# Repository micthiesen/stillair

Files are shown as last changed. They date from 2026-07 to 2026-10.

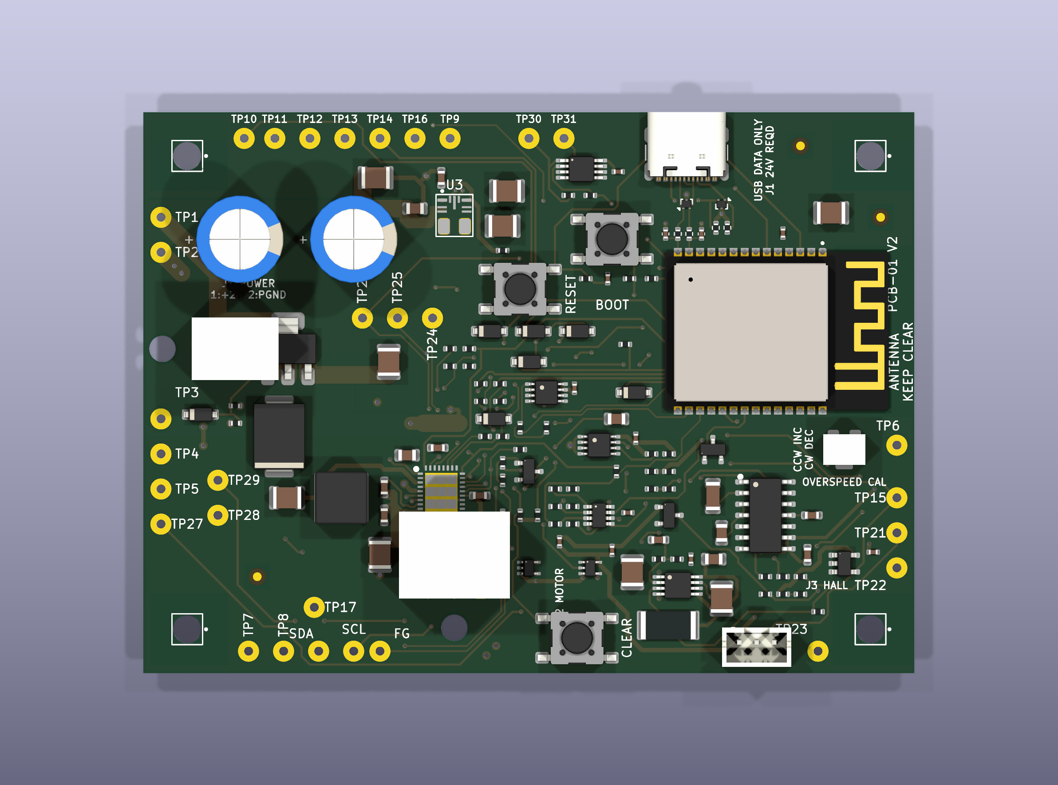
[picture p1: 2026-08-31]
pcb/pcb-01-v2/fab/assembly-preview-3d.png

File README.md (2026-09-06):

# stillair

Custom 44-inch direct-drive ceiling fan for quiet overnight air mixing: CubeMars GL100 KV10
gimbal motor, TI MCF8316D sensorless FOC on a custom controller board, ESP32-C6 supervisor
with local-only Apple Home control via Matter (rs-matter), and an independent analog
overspeed backstop.

This repo is the canonical source for everything except the OnShape 3D model:

- [`docs/`](docs/overview.md) — the full design dossier (start at the overview; current work
  state in [docs/STATE.md](docs/STATE.md))
- [`bom/`](bom/README.md) — parts list with purchase tracking
- [`testing/`](testing/README.md) — commissioning matrix with sign-off fields
- [`firmware/`](firmware/) — Rust `no_std` ESP32-C6 supervisor (stub; contract in
  [docs/controls.md](docs/controls.md))
- [`pcb/`](pcb/README.md): authoritative tscircuit source for new boards plus downstream KiCad
  routing and production outputs (requirements in [docs/electrical.md](docs/electrical.md))
- [`cad/`](cad/README.md) — fabrication outputs (specs in [docs/parts.md](docs/parts.md))

Firmware: `cd firmware && cargo build` (stable Rust; flashing via `cargo run` uses espflash).

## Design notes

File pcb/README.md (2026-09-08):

# PCB

PCB design source and production projects. For new boards, committed tscircuit code owns component
definitions, schematic connectivity, board specifications, and placement. KiCad owns downstream
routing, unsupported fabrication detail, checks, and outputs. The complete electrical requirements
are [../docs/electrical.md](../docs/electrical.md), and the V1-to-V2 gate list is at the bottom of
that doc.

## Projects

- `pcb-01/` — the controller board (**PCB-01**). Captured, routed, and ordered from JLCPCB
  2026-07-30 (order W2026073105230212).
- `pcb-01-v2/` — the fresh **PCB-01 V2** controller project. It is intentionally not cloned from
  V1. Capture, placement, routing, silkscreen, and the submission package are complete; its exact
  authority is [`docs/pcb-01-v2.md`](../docs/pcb-01-v2.md) and its order procedure is
  [`pcb-01-v2/fab/ORDERING.md`](pcb-01-v2/fab/ORDERING.md).
- `pcb-02/` — the 24 × 8 mm DRV5033 Hall daughterboard (**PCB-02**). Created 2026-07-30:
  schematic captured (ERC clean), 2-layer board set up (outline, M2 hole pair as the BR-100
  datum, JLCPCB rules). Ships as its own small order — PCB-01 already went out separately.
- `pcb-03/` - the optional 39.75 x 21.00 mm e-paper display bridge (**PCB-03**). It converts PCB-01
  V2's four-wire temperature I2C expansion path to the SPI and sideband signals used by a
  Waveshare 1.54-inch black/white module. Its authority is
  [`docs/pcb-03.md`](../docs/pcb-03.md); it is a two-layer bare board for hand assembly. Upload
  and quote settings are in [`pcb-03/fab/ORDERING.md`](pcb-03/fab/ORDERING.md).

## Tooling and authority

The pinned local tscircuit toolchain lives in this directory. Run its viewer locally so code and
reviewed placement edits remain in the checkout. The **`/pcb` skill** at
[`.agents/skills/pcb/SKILL.md`](../.agents/skills/pcb/SKILL.md) defines authoring, review, initial
handoff, and later ECOs. KiCad 10 and the project-scoped Konnect server remain available only for
the downstream phase.

An initial handoff exports a new KiCad seed into staging. Once routing starts, a new export must
never overwrite the production board. Later tscircuit changes become an explicit stable-identity
ECO, applied through KiCad/Konnect/native APIs and checked to preserve unrelated routes, vias,
zones, rules, and UUID-bound waivers. Each board declares unsupported downstream work in
`design/kicad-augment.json`.

PCB-01, PCB-01 V2, PCB-02, and the already released PCB-03 remain legacy KiCad-authoritative
projects. PCB-03's new `design/` source recreates it only as a workflow validation fixture through
the KiCad handoff boundary.

Fabrication is planned through JLCPCB; JLCPCB assembly vs hand-population is TBD (prefer
footprints/parts in the LCSC catalog where it doesn't compromise the design, so the PCBA
option stays open). The Hall daughterboard (18 × 8 mm, DRV5033) is a second tiny board that
should ride in the same order/panel. A possible V2 reshape to a horizontal donut board is
noted in the handoff doc.

## Human probing map

PCB-01 test-point and connector locations are retained in `pcb-01/probe-map.json`; the human
workflow, ground-domain rules, and temporary-wire policy are in [`docs/probing.md`](../docs/probing.md).
Use `pcb/tools/probe_guide.py TP7`, `pcb/tools/probe_guide.py J8`, or
`pcb/tools/probe_guide.py TP2 --mode resistance` to print a complete one-step instruction. Run
`pcb/tools/probe_guide.py --verify-board` after any layout revision so the retained map cannot silently
drift from the board.

## JLCPCB order config

The bullets below are the historical V1 research record. They do not control PCB-01 V2. V2 uses
the impedance-controlled JLC041621-7628 build, exact POFV attachments, and assembly split in
[`pcb-01-v2/fab/ORDERING.md`](pcb-01-v2/fab/ORDERING.md).

- Standard 4-layer 1.6 mm with the order-form copper dropdown set to **2 oz outer / 1 oz
  inner** (the V1 order did not use a canned JLC04161H stackup; sanity-check the resulting
  dielectric build in the quote tool). ENIG and the Ø3.2 NPTH holes are unrestricted.
- **2 oz raises min trace/space to 0.15–0.16 mm** — check routing under the ESP module
  fits. The common fallback for a ~2 A board is 1 oz outer with ≥1.5–2 mm pours, avoiding
  the 2 oz penalty entirely; decide at capture.
- MCF exposed-pad thermal vias: request **POFV (copper-filled/capped vias)**, drills
  0.25–0.35 mm — a paid special process at 4 layers; budget it.
- Ballpark: ~$80–150 for qty 5 bare boards with the above; 2 oz doesn't block PCBA.

## Footprint/symbol sourcing (researched 2026-07)

Clean pulls from KiCad official libs: ESP32-C6-MINI-1 (needs KiCad ≥8.0.9), GCT USB4105
(note: **top-mount** — confirm against the housing), TC2030-NL, JST PH and SH/SRSS
connectors, Coilcraft LPS4018, Panasonic EEU-FR (parametric CP_Radial), SMC TVS, SOIC-14,
SOT-23 variants.

Needs Ultra Librarian download + datasheet verification: **MCF8316D** (rectangular-body
VQFN-40 RGF — KiCad's stock VQFN-40 is the wrong shape), **TPSM365R6** (RDN QFN-FCMOD).
Hybrid cases: TPS7A1601A (KiCad footprint, UL symbol; check EP copper vs TI's land),
SN74LVC1G74 DCT/SM8 (KiCad's generic SSOP-8 pad span is wider than TI's spec — use TI/UL's).
All TI discrete symbols come from SnapEDA/UL (pinouts are part-specific). Molex: the ordered
headers are the **right-angle** variants (43045-0200, 43650-0300) — use the horizontal
footprints, not vertical.

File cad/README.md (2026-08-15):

# CAD

Fabrication outputs for the custom mechanical parts: 2D profiles for laser/waterjet (MP-100,
KD-100, MR-100, LS-100, BR-100 flat pattern), CNC files (MC-100, RH-100, SP-100, BL-100
router files), and print files (BA-10/12/14, ENC-100, optionally EB-100).

The full 3D assembly is modeled in **OnShape** and does not live in this repo; export STEP/PDF
here when parts approach fabrication release. Dimensioned specs for every part:
[../docs/parts.md](../docs/parts.md). Do not release motor-dependent metal before the
fabrication gates at the bottom of that doc clear.

## Released files

| Part | Files | Status |
|---|---|---|
| MP-100 | `MP-100_revA.step`, `MP-100_revA.pdf` | Received + owner-accepted 2026-08-14 |
| ST-100 | `ST-100_revA.step`, `ST-100_revA.pdf` | Received + owner-accepted 2026-08-14 |

Name every export `<PART>_rev<X>.<ext>` and commit it **as sent**. The point is that a later
revision diffs against the geometry that was actually quoted, not against the live OnShape
model, which keeps moving.

## Ordering at JLCCNC

Learned ordering MP-100 (2026-07-27). The CNC service is **jlccnc.com**, separate from the
PCB side.

**Send two files.** A STEP (AP214) drives the instant quote and the geometry; a **PDF drawing**
carries everything a STEP cannot hold — threads, tolerances, finish, and face assignment.
JLC's review engineers cross-check the two by hand and will query any disagreement.

**Attach the PDF twice.** Once as the general 2D drawing, and again to the `+ Add file` slot
that appears under **Threads → Yes**. That slot is the "tapping document" and it is easy to
miss; with Threads set to Yes and no file, tapped holes get quoted as plain drills.

**Dialog settings that worked** (adapt material/finish per part):

| Field | MP-100 value | Note |
|---|---|---|
| Material | Stainless Steel → SUS304 | Aluminum 6061 is the sticky default — verify on the quote line, stainless runs 2–3× the price |
| Surface Finish | Brushing | Anodizing is aluminium-only; passivation is not offered for 304 |
| Tightest Tolerance | ±0.10 mm | Only buy ±0.05 if a callout truly needs it |
| Appearance | Standard | Ra 1.6 is not worth paying for on a hidden part |
| Threads | Yes + PDF attached | See above |
| Sub-assembly | No | |

**Their DFM rules that shaped the design** (worth designing to up front rather than
answering a query about later):

- Blind tapped holes want **≥ half the nominal diameter left unthreaded** at the bottom.
  This is what drove MP-100's ten taps to M3 × 0.5 at 3.5 mm thread in a 5.0 mm drill; M4
  needs 2.0 mm of run-out and could not get it inside a 6 mm plate.
- Effective thread length **≤ 3 × hole diameter**.
- Tapped holes must sit in the interior of the part, clear of edges.
- Default tolerance is **±0.1 mm** if the drawing states none — tighter than ISO 2768-m, so
  a 2768 block is a ceiling, not a floor.

**What JLC does not hold: form tolerances.** Flatness, runout, concentricity and true
position are quoted to nothing. They live in the PDF as intent and must be inspected on
arrival. This is the reason SP-100 (0.05 mm concentricity TIR) and MC-100/RH-100 (0.08 mm
flatness and TIR) are poor fits for JLC even though MP-100 was a good one.

**Drawing checklist** (what MP-100's PDF carries):

1. Views labelled `CEILING FACE` and `UNDERSIDE` in words, plus a note assigning every
   one-sided feature to a face. A flat disc looks identical from both sides.
2. A hole table with signed X/Y per hole. Coordinates cannot be mirrored the way
   "6× at 45°, 60° spacing" can.
3. A note fixing the angular datum and direction in prose, as mirror insurance.
4. A note that the hole table covers tapped holes only, if through-holes are dimensioned
   on the views instead.
5. ISO 2768-mK block, form tolerances, minimum internal corner radii, material and finish.

**Turned-part modeling + drawing notes** (learned on ST-100 rev A, 2026-07-28):

- Model the thread-entry chamfer as the Hole feature's **countersink** (Ø7 × 90° for M6):
  it exports in the STEP and lands in the drawing's hole callout automatically.
- Second-end tap on a turned part: **Mid plane** between the end faces + **Feature mirror**
  of the Hole feature — one edit drives both ends.
- In OnShape's tapped-Hole dialog the tap fields (Tapped depth, Tap clearance) are below
  the fold — scroll; the visible 13.44/90° pair is the countersink, not the thread.
- Drawings: the **Datum** tool attaches to the OD silhouette edge or the Ø dimension; the
  **Geometric tolerance** tool only attaches its leader *during placement* (hover-click the
  edge while the dialog is open) — a frame placed floating cannot be attached afterwards.
- Fill the title block TITLE/DWG NO fields before export (left empty on ST-100 rev A;
  harmless, but the shop sees it).

**Gotcha that cost a rebuild:** OnShape hole tables snap their origin to real geometry, so
an under-constrained centre bore silently offsets every coordinate in the table. MP-100's
bore sat 0.64 mm low in Y and the table inherited it. If the table's origin will not snap
where it should, suspect the model, not the drawing — and check that the base sketch is
fully defined before trusting any exported coordinate.

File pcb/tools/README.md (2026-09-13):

# PCB tools

The shared native/workflow helpers are available for future source/native changes.
Stillair has not configured `pcb/workflow.json` or a readiness profile for them.
Installing the tools does not migrate or reaccept PCB-01, PCB-01 V2, PCB-02 or the
released PCB-03. These remain KiCad-authoritative and use their existing commands
and release evidence. Do not copy Crystal Shim's profiles or geometry here.

## One checked change lifecycle

Agree on the visual direction before detailed placement, then record dimensions,
mounting, connector directions, layer roles and assembly limits in canonical specs.
Keep images as references; they do not select circuitry or exact component geometry.
Define every required preparation check before assigning implementation so paste,
service labels and export requirements do not reopen an otherwise finished handoff.

| Stage | Result |
| --- | --- |
| `doctor` | Installed capabilities and project configuration are checked before choosing an automation path. Unsupported operations stay explicit. |
| `begin` | Retains the adopted lock, native file hashes and before snapshot. Begin before editing the native project. |
| `plan` | Rebuilds source, compares the accepted baseline and records the complete target/ECO with its input hashes. |
| `draft-transaction` | Drafts same-side placement changes only and rejects every other plan change. Review associated track/via/zone UUIDs explicitly. A draft is not application or acceptance. |
| `apply` | Runs the supported native transaction against the bound before state, saves and reopens the candidate, then verifies saved readback. |
| `validate` | Runs source checks, strict ERC, source/native parity, fresh native DRC, the complete preparation profile and fresh renders. It does not modify production native files. |
| `review` | Records actual inspection of the current validation/renders across visual contract, schematics, placement/copper and assembly/process. |
| `accept` | Rechecks current inputs, complete checks and resolved review, then advances the existing handoff lock once. |
| `status` | Reports the retained stage; a prior success does not excuse changed inputs. |

The coordinator is `pcb_workflow.py`; run `python3 pcb/tools/pcb_workflow.py --help`
for its current flags. `begin` through `accept` coordinates an ECO to an adopted
source/native handoff. First adoption still uses the staged `tscircuit_handoff.py`
export and acceptance path. A standalone `validate` can audit an existing configured
board but cannot invent the baseline and plan needed for acceptance.

Review can be performed by the agent or owner within existing authorization. The
review record names the reviewer, binds the exact validation object and records
concrete findings/evidence in all four scopes. The tool cannot inspect a picture
or resolve an electrical question on the reviewer's behalf. Apply corrections,
validate again and review the new evidence before final acceptance. Tool failures
and unsupported capabilities do not create new permission gates.

The review JSON has this shape. Replace each placeholder with actual inspection
findings and the current `validation` value from `run.json`:

```json
{
  "validation": "<current validation object SHA-256>",
  "reviewer": "<reviewer name>",
  "scopes": {
    "visual_contract": "<visual and dimensional findings>",
    "schematics": "<schematic and electrical findings>",
    "placement_and_copper": "<placement and layer render findings>",
    "assembly_and_process": "<paste, labels, stack and order findings>"
  },
  "unresolved_findings": []
}
```

## Evidence and configuration

A run has a small `run.json` index and `objects/<sha256>.json` evidence objects.
Identical retained JSON content shares an object within that run. Keep the index,
referenced objects and reviewed renders together. Do not copy repeated full
snapshots into successive closure reports or substitute a bare `passed: true`.
The coordinator binds source, native project files, canonical contracts, reference
images, profiles and checker code. A changed input or modified evidence invalidates
stale validation/review. Canonical docs describe the current target; STATE points to
the current acceptance and remaining routing/commissioning work.

`pcb/workflow.json` and `pcb/tools/readiness-profiles.json` are project-owned.
They select board paths, source commands, specification/image inputs and exact
preparation requirements. They are not shared copies. A missing or unsupported
profile is an explicit configuration failure, never a skipped audit or inherited
permission to use another board's limits.

A reviewed source-checker limitation, when a project needs one, binds the exact
command, nonzero exit code, stdout digest and stderr digest. Its raw failure and
reason remain in the evidence, with required native counterchecks. Any changed
output fails closed. This is an accounted-for checker limitation, not a clean source
check or permission to ignore further findings. Never inherit another project's
limitation record.

`pcb_readiness.py` performs read-only checks of geometry, physical stack, planes,
vias, native rules, routing policy, paste, labels and declared exclusions. It uses
native geometry plus saved settings where SWIG lacks a readable API. Profiles
must declare all supported check categories. Project callbacks retain specialized
checks without embedding product rules in the generic engine. This is preparation
validation, not zero-unconnected routed acceptance or physical commissioning.
Inspect the declared assembly/export contract during final review as well.

## Verified write helpers and limits

Prefer a supported helper over GUI repetition or a new board-specific script.
Discover capabilities first and test uncertainty on explicit scratch copies.
Never infer support from the name of a tool or from a success flag alone.

| Operation | Supported path and limit |
| --- | --- |
| Footprint moves and associated copper; rectangular outlines | `kicad_native.py`, with UUID-bound from/to geometry and explicitly associated items. |
| Pad paste, existing footprint fields, labels | Verified native transaction operations with saved readback. |
| Straight tracks, through vias, simple zones | Verified native operations; complex zone holes, blind/buried/microvias and arbitrary geometry are not implied. |
| Existing netclass sizes | Verified native settings operation; netclass assignment changes are not currently supported. |
| Interactive router preferences | No verified native writer. The in-memory board settings do not prove the GUI session preference was saved in `.kicad_prl`. |
| Existing schematic Value, MPN, Description, Datasheet and Footprint | `kicad_schematic.py`, one explicit leaf sheet and existing string properties only. |
| Schematic Reference rename, new properties, BOM/position/DNP flags | Not supported by the schematic bridge. Use an independently verified operation or the GUI and recheck parity. |
| Physical stack materials/thickness | No verified automated writer in these helpers. KiCad 10 SWIG exposes an opaque stack descriptor; enabling layers does not set the physical stack. |
| Custom-rule file installation | No verified native installer in the helper. Use the supported GUI path; native CLI DRC verifies the installed adjacent rules. |
| Footprint replacement | Not implemented by the generic native transaction. Requires source-aware footprint/pad identity mapping and a verified application path. |

Read exact operations with:

```sh
sh pcb/tools/kicad_python.sh pcb/tools/kicad_native.py capabilities
python3 pcb/tools/kicad_schematic.py --help
```

Use `sh pcb/tools/kicad_python.sh pcb/tools/kicad_native.py inspect --board PATH`
to obtain UUIDs, exact current states and input hashes without writing a discovery
script. The returned saved state supplies transaction `from` values.

Native transactions bind every project input in `before_files`, preflight the whole
batch, load the actual project settings, fill, save and reopen a scratch candidate,
and compare each requested result and saved readback before publication. Native publication replaces files
individually; it is not atomic across a project. Transaction/editor locks and stale
hash checks protect known concurrent changes. Keep the project closed during an
apply. A publication failure attempts guarded rollback and retains recovery files
when it cannot restore safely. Read the reported state instead of retrying blindly.
A native-application receipt alone does not prove electrical correctness, DRC or
acceptance; the external validator and workflow gates establish those separately.

Schematic batches use Konnect's local stdio MCP binary, not an external account.
The wrapper runs the batch on a scratch leaf, verifies every requested property
and the entire semantic tree, compares fresh native net connectivity, and atomically
publishes only verified Konnect-produced bytes. It refuses ambiguous/duplicate
properties, missing fields, partial results, stale inputs and unexpected changes.
Quotes, backslashes and control characters in edited old/new values are deliberately
unsupported while the installed upstream string handling remains unsafe.

Example request for an existing leaf property:

```json
{
  "schema_version": 1,
  "before_sha256": "<SHA-256 of the current leaf schematic>",
  "edits": [{"reference": "J1", "fields": {"MPN": "NEW-PART-NUMBER"}}]
}
```

Pass this JSON to `kicad_schematic.py leaf.kicad_sch request.json --receipt receipt.json`.
Use `--konnect-command` and `--kicad-cli-command` with JSON argv arrays to select the
installed executables. A root schematic containing hierarchical sheets is not the
leaf containing a component. All wrappers use argv arrays rather than shell code.

The [shared Konnect skill](../../.agents/skills/konnect/SKILL.md#choose-the-write-path-before-implementation)
links the inspected 0.2.1 implementation: single-component `fields` are ignored,
annotation appends duplicate keys, batch edits can partially succeed or corrupt
quoting, and design/layer-rule setters write the wrong KiCad 10 locations. These
are measured limits, not reasons to repeat the same failing calls.

## Stillair commands and existing handoff

Use the local PCB-03 source checks and established board-specific tools below.
Before enabling the coordinator, define a Stillair-owned profile for a compatible
adopted source handoff, supported readiness checks, canonical specifications and
actual runtime commands. Missing configuration is explicit; no released board has
been implicitly audited by this sync.

The generic stdlib suites run without a board:

```sh
python3 -m unittest discover -s pcb/tools -p 'test_kicad_*.py'
python3 -m unittest discover -s pcb/tools -p 'test_pcb_*.py'
```

Native integration tests require an installed KiCad runtime and use scratch
projects. Record actual runtime evidence separately from skipped tests.

`tscircuit_handoff.py` is the new-board boundary. It validates normalized authoritative source,
stages the one-time KiCad export, records an accepted lock, and plans later ECOs without writing a
production KiCad project.

Acceptance is byte-bound to every staged `.kicad_*` file listed in `handoff-receipt.json`. Moving
the complete stage directory is safe, but changing its board, root schematic, or child schematic
after staging makes `accept` fail. Native staging and acceptance are currently macOS-only.

The initial exporter fixture may retain only the differences explicitly declared by
`schematic_cleanup`; its receipt lists each reference, expected value, and observed value. After
performing that cleanup in KiCad, run this against the current root schematic before routing or
fabrication:

```bash
python3 pcb/tools/tscircuit_handoff.py verify-schematic-cleanup \
  pcb/dist/pcb-03/design/design-manifest.normalized.json \
  --augmentation pcb/pcb-03/design/kicad-augment.json \
  --schematic /path/to/current/root.kicad_sch \
  --output /path/to/schematic-cleanup-report.json
```

The command invokes the discovered `kicad-cli` itself and derives the XML netlist and JSON ERC in
one temporary run, so separately supplied or stale reports cannot pass. It requires error,
warning and excluded severities, rejects ignored checks and any excluded finding, and
then requires exact references, values, symbol IDs, footprints, MPNs, Datasheets, pin sets, net
endpoints, and a clean ERC result. A failing report must not be used to start routing.

`check_drc.py`, `jlc_fab.py`, `refill_zones.py`, `render_board.sh`, `probe_guide.py`, and the
board-specific `pcbnew` augmentation scripts are downstream KiCad tools. Their writes use KiCad's
native API and must follow the protected-file and preservation checks in the `/pcb` and `konnect`
skills.

The PCB-01 placement planners (`board_model.py`, `check_moves.py`, `check_plan.py`,
`make_briefs.py`, `park_unplaced.py`, `place_targeted.py`, and `validate_group.py`) are retained only
as legacy analysis/history. They are not an authoring or update path for a tscircuit-first board.
The two scripts that directly rewrote protected KiCad text were removed; git history retains them.

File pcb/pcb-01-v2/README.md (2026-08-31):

# PCB-01 V2 KiCad project

Production-intent KiCad 10 project for the 88 x 64 mm PCB-01 V2 controller. The schematic,
footprints, exact ratsnest, four-layer board setup, placement, rule areas, copper zones, keepouts,
fiducials, silkscreen, and assembly metadata are complete. All 166 footprints are on the component
side. Routing and zone fill are complete. The reviewed headless DRC has zero active violations and
zero unconnected items; its 21 exact UUID-bound exceptions are documented in
`../tools/check_drc.py`.

The frozen circuit and layout authority is
[`docs/pcb-01-v2.md`](../../docs/pcb-01-v2.md). Do not import V1 routing, placement, zones, probe
coordinates, or DRC waivers.

## Routing rules retained for review

Open `pcb-01-v2.kicad_pro` and route in the PCB Editor. The concise interactive routing checklist is
<https://mcp.syas.ca/boris/artifacts/art_eon2bpkmslvmtf6wfpa>.

Use the deliberately small routing vocabulary encoded in `pcb-01-v2.kicad_dru`:

| Use | Track | Via |
|---|---:|---:|
| Signals and sensitive analog | 0.20 mm | 0.60/0.30 mm |
| Local rails and 3V3 | 0.50 mm | 0.60/0.30 mm |
| RAW24, VM24, and PGND | 2.00 mm | 1.00/0.50 mm |
| PHASE_U/V/W | 2.00 mm | none |
| USB D+/D- pair | 0.20 mm, 0.20 mm gap | none |

The only narrower power exceptions are the named, tightly bounded U1 and U3 pad-escape areas. The
rules require the complete track item to remain inside the area. Widen immediately after the pad.
U1's three PGND returns use reviewed 0.60/0.30 mm escape vias because its 0.50 mm pin pitch cannot
fit the ordinary 1.00/0.50 mm power via while preserving phase clearance. The headless DRC wrapper
waives only the diameter and drill findings for those three exact via UUIDs.
Do not weaken or delete the PGND routing boundary, antenna keepout, 0.80 mm noisy-to-sensitive
clearance, mounting-hole keepouts, or fiducial keepouts to complete routing.

The stack is 1.6 mm FR-4, four layers, with 2 oz outer and 1 oz inner copper. In1.Cu is the AGND
plane. In2.Cu contains the 3V3 region and motor-region copper defined in the board. Ordinary minimum
clearance is 0.20 mm; 24 V and motor-phase clearance is 0.25 mm; copper-to-edge is 0.50 mm.

## Current verification state

- ERC: zero violations.
- Schematic parity: 159 refs, 78 named nets, and 411 endpoints match the frozen schedule.
- Board: 166 top-side footprints, completed routing, filled zones, and no unconnected items.
- DRC: zero active violations and zero unconnected items, with 21 exact reviewed exceptions for
  bounded pad escapes and three U1 PGND escape vias.
- Probe map: 31 test points and four pin-mapped connectors match the board.
- Assembly export: 55 machine BOM lines, 119 top-side CPL placements, and six hand refs.

After any board edit, refill all zones and rerun the complete release generator. It refuses to emit
orderable Gerbers if ERC, schematic parity, DRC, or probe-map parity fails.

Useful checks from the repository root:

```bash
kicad-cli sch erc pcb/pcb-01-v2/pcb-01-v2.kicad_sch
python3 pcb/tools/check_drc.py
kicad-cli sch export netlist --output /tmp/pcb-01-v2.net pcb/pcb-01-v2/pcb-01-v2.kicad_sch
python3 pcb/tools/check_v2_capture.py /tmp/pcb-01-v2.net
python3 pcb/tools/probe_guide.py --map pcb/pcb-01-v2/probe-map.json \
  --board pcb/pcb-01-v2/pcb-01-v2.kicad_pcb --verify-board
python3 pcb/tools/jlc_fab.py pcb-01-v2
```

## Fabrication handoff

The tracked `fab/` directory contains the exact LCSC map, assembly/hand manifests, machine BOM,
CPL, POFV coordinates, fabrication notes, and a generated four-page assembly locator. U1's twelve
0.30 mm pad-41 holes require epoxy fill and copper capping. U1 pad 41 retains its submitted top
solder-mask aperture for soldering, with no separate bottom aperture. The Excellon and KiCad
coordinate conventions are identified in the generated POFV attachments. U3 pads 4 and 5 are
mask-defined and require JLC engineering confirmation.

Run `python3 pcb/tools/jlc_fab.py pcb-01-v2` immediately before upload, verify
`fab/release-manifest.sha256`, inspect the generated Gerbers, drill map, BOM, CPL, POFV attachments,
and assembly orientation guide, then follow `fab/ORDERING.md` and `fab/fabrication-notes.md`.

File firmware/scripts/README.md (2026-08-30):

# Commissioning scripts

Build the host harness once, then run each file against the same long USB harness used for
bench or ceiling work:

```sh
cd firmware
cargo build
target/debug/stillair --port /dev/cu.usbmodem2101 script scripts/01-board-smoke.txt
```

The numbered release scripts 01 through 06 remain the normal commissioning flow. The retained
unloaded-tuning profiles are evidence-oriented bench tests:

- `18-unloaded-startup-camera.txt`: one complete 35 RPM start, hold, and normal stop.
- `22-unloaded-timestamped-ladder.txt`: both rising and falling speed plateaus.
- `23-unloaded-reverse-ladder.txt`: reverse startup, range, and normal stop.
- `25-unloaded-start-repeatability.txt`: two complete starts and stops per direction.
- `26-unloaded-100-endurance.txt`: ten-minute continuous midrange hold.
- `27-unloaded-140-endurance.txt`: five-minute upper-range hold for the 19.4 V bench source.
- `29-unloaded-100-estimator.txt`: known-stable 24 V observer/current reference point.
- `30-unloaded-24v-ceiling-diagnostics.txt`: guarded 100/140/160/170 RPM ladder with an
  observer/current sample at every rung.
- `31-unloaded-acoustic-threshold.txt`: guarded 100/120/130/140 RPM comparison used when a
  candidate changes high-speed commutation noise; it deliberately stops below 160 RPM.
- `32-unloaded-speed-pi-candidate.txt`: shorter 100/130/140 RPM A/B profile for iterating one
  speed-loop gain while retaining a stable reference and pre-threshold control.
- `33-unloaded-140-observer-onset.txt`: continuous q-axis/BEMF observer capture through the
  apparent 140 RPM optical-hunting onset; precise Hall timing later proved it was tracker slip.
- `47-unloaded-full-range-tach.txt`: 100/140/160/170 RPM plateaus with sampled Hall
  edge-period estimates and MCF FG as the shaft-speed authorities.
- `48-unloaded-pwm-acoustic-candidate.txt` and `49-unloaded-pwm-top-speed-candidate.txt`:
  matched-speed camera-audio, Hall, FG, and wall-power comparisons for PWM tuning.
- `50-unloaded-170-endurance.txt`: ten-minute worst-case unloaded hold at the user ceiling.

A failed command stops a file and returns non-zero. `wait speed` requires both the commanded
ramp and three consecutive FG samples in range, so merely crossing a setpoint does not count
as arrival. `dwell` requires a live 1 Hz telemetry heartbeat and a continuously running state
while an external camera and power logger gather the continuous evidence.

`08-flash-and-unloaded-profile.sh` is the common synchronized acquisition runner. Its default
`STILLAIR_CONFIG_MODE=stage` preserves the unloaded workflow: it builds, flashes, power-cycles,
stages the volatile image, and runs one of those profiles. `STILLAIR_CAMERA_URL` is required for
synchronized recording and physical-motion analysis. The credential-bearing URL is fed to FFmpeg through a private
file descriptor rather than exposed in its arguments or logs. The wrapper waits for a real
camera frame and a live Utility Plug power sample, retains camera audio when the stream provides
it, records the camera-to-motor offset, and fails if the camera, plug logger, controller
telemetry, tracking, or a relevant direction/stall/plateau gate fails. Optical speed is scored
through 140 RPM. Above that, repeatable orientation-specific tracker slips make precise Hall
edge timing and MCF FG the speed authorities while the camera remains the gross-motion guard.
Its deadline is
derived from the selected profile, so endurance profiles do not need a manual timeout override.
Any failed command releases the serial client, attempts controller disarm, then independently
switches off the exact Kasa `Utility Plug`; a successful run leaves the 24 V supply available.
An unloaded run stages and read-back-verifies the volatile MCF image. A loaded reference run uses
`STILLAIR_CONFIG_MODE=verified`, requires the stored golden image to verify, and refuses to replace
a failed baseline with a staged image. `STILLAIR_SKIP_FLASH=1` skips only the ESP build/flash.
Timestamped dwell
profiles also align their camera motion and 1 Hz AC power samples to the same motor timeline, so
`analyze_profile_plateaus.py` and `analyze_profile_power.py` report physical regulation and input
power for the same settled windows. Use
`utility-plug.sh status|on|off|cycle` for manual control and `utility-plug.sh log --for SECONDS`
for 1 Hz AC voltage/current/power evidence. The controller runs inside the Boris Homebridge
container, where Kasa credentials already live, refuses any device other than the pinned Utility
Plug identity and address, and reconnects boundedly after transient TPAP failures without running
periodic rediscovery through an active evidence stream.

The runner uses the ESP32-C6 native USB Serial/JTAG port. Power the board normally, hold BOOT, tap
RESET, release BOOT, then run the flash step. USB VBUS does not power the board. Set
`STILLAIR_PORT=/dev/cu...` to override detection. There is no FTDI/UART transport, VID/PID-specific
adapter logic, or RTS/DTR automation.

`check-mcf-presence.sh` is the safe repeated check after connector cleanup or probing. It powers
the controller, holds one serial connection through boot, passes only when the MCF8316D answers the
firmware's wake-and-address scan, and returns Kasa power off on every exit. Override automatic board
port detection with `STILLAIR_PORT=/dev/cu.usbmodem...` when needed.

`check_board_usb.py` is the permission-independent native-USB check. It passes only when macOS's
live I/O Registry contains exactly one ESP32-C6 USB Serial/JTAG device (VID `0x303a`, PID `0x1001`)
continuously for 0.5 seconds. Serial `/dev` nodes are reported separately and do not decide the
enumeration result. Run it while connecting or resetting the board:

```sh
firmware/scripts/check_board_usb.py
```

Exit 0 means enumerated, 1 means not detected during the polling window, 2 means ambiguous or
unstable, and 3 means the host probe itself failed. A nonzero result never claims which hardware
element caused the failure.

For recovery or A/B work, script 03 begins with `config stage`. This loads and
read-back-verifies the reviewed GL100 first-spin settings in volatile shadow only. It must be
repeated after every motor-power cycle, and it never commits EEPROM. A fresh unverified
controller remains in `SafeBoot`; this prevents zero factory speed-loop gains from invoking
implicit MPET on an ordinary run command. Script 02 remains on hold until the volatile image
has also been reviewed for loaded MPET.

Scripts 04 through 06 are loaded release tests. They begin with `config check` and require the
committed golden image; staging the provisional image there would overwrite loaded tuning.

## Autonomous loaded reference

`09-run-loaded-profile.sh` is the fail-closed entry point for the first exposed loaded capture.
It validates the profile before connecting to hardware, forces verified-golden mode, and requires
the fixed dedicated microphone, OWON capture, camera motion guard, controller telemetry, physical
Hall/FG, and Utility Plug evidence. It defaults to `51-loaded-golden-baseline.txt`, which measures
50, 60, 80, 120, and 170 RPM and returns to verified `idle_off`. It will not accept `config stage`,
`config apply`, raw register writes, an out-of-range speed, an unsafe direction change, or a profile
that lacks a final stopped-state proof.

```sh
STILLAIR_DRY_RUN=1 scripts/09-run-loaded-profile.sh

STILLAIR_CAMERA_URL='rtsps://…' \
STILLAIR_SCOPE_ISOLATED_CONFIRMED=1 \
scripts/09-run-loaded-profile.sh
```

When `STILLAIR_CAMERA_URL` is unset, the runner reads the RTSP URL from
`${XDG_CONFIG_HOME:-$HOME/.config}/stillair/camera-url` or the path named by
`STILLAIR_CAMERA_URL_FILE`. Keep that file outside the repository and readable only by its owner.

The microphone defaults to the AVFoundation device name `Razer Seiren V3 Mini`; override
`STILLAIR_AUDIO_DEVICE` if the enumerated name differs. Audio is retained as mono 24-bit/96 kHz
WAV and analyzed at 48 kHz, preserving comparison bands through 20 kHz. The scope recipe defaults
to `scope-loaded-startup.json`: SOX and FG at 250 ksample/s in discrete 5,000-sample frames. Its
range, offset, ground references, and isolated VDS1022I model must be physically confirmed before
setting `STILLAIR_SCOPE_ISOLATED_CONFIRMED=1`. The capture uses the Python API from
`florentbr/OWON-VDS1022` pinned at commit `4c67805713906c20b4414b4225fd293adea4cb05`; it records
inter-frame arrival gaps and never describes the frames as continuous acquisition.

Each successful run prints a `run_dir` under `STILLAIR_EVIDENCE_ROOT` (default `/tmp`). Its
`manifest.json` records the git commit, timing anchors, configuration mode, file sizes, and SHA-256
hashes for every retained file, including each scope frame. A missing or malformed required source
fails the run. Both loaded wrappers require the repository to remain clean and on the same commit
for the complete run, so the recorded commit identifies the firmware source rather than merely the
latest nearby revision. The baseline entry point deliberately captures the untouched golden reference only. Loaded
candidate generation remains a separate tuning step.

After the untouched reference is secured, run one allowlisted golden-derived candidate with the
same evidence stack and matched ladder:

```sh
STILLAIR_DRY_RUN=1 scripts/10-run-loaded-candidate.sh pwm-30khz

STILLAIR_CAMERA_URL='rtsps://…' \
STILLAIR_SCOPE_ISOLATED_CONFIRMED=1 \
scripts/10-run-loaded-candidate.sh pwm-30khz
```

`10-run-loaded-candidate.sh` accepts `pwm-20khz`, `pwm-25khz`, `pwm-30khz`, `pwm-40khz`,
`pwm-50khz`, `pwm-60khz`, `deadtime-off`, `deadtime-on`, `slew-125v-us`, or `slew-200v-us`.
It verifies the stored golden image before evidence collection, then `config tune` restores that
complete image in volatile shadow, changes exactly the named reviewed field, rechecks the preserved
golden bits, and reports the distinct `config=tuning` verdict. The matched motor profile is
`52-loaded-acoustic-candidate.txt`. The run manifest records the candidate name, application time,
and device reply. No candidate path can commit EEPROM. Retain the golden run as the A/B control and
never promote a finalist until it repeats the release gates.

`02-mpet-and-capture.txt` prints the raw extraction result and then a paste-ready configuration
image. Review that capture before committing or applying it. MPET itself updates shadow
registers only and does not spend an EEPROM cycle.

The 35 RPM design target was rejected for loaded use after one arbitrary-position start rocked
without acquiring. The provisional released floor is 50 RPM; scripts that retain a 35 RPM bench
rung are unloaded evidence profiles, not the user operating contract.

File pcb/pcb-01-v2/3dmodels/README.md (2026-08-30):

# PCB-01 V2 local 3D models

- `ESP32-C6-WROOM-1.STEP` is Espressif's module model. Its corner-origin model is offset in the
  footprint by (-9, -12.75) mm so the 18 x 25.5 mm body aligns with the official land pattern.
- `J1_43045-0200_ENVELOPE.stp` and `J2_43650-0300_ENVELOPE.stp` are conservative body-envelope
  solids built from the exact KiCad F.Fab extents and Molex customer-drawing maximum height. They
  replace nonexistent KiCad package paths and validate board/enclosure access; they are not detailed
  cosmetic connector models.
- `RV1_3224W_ENVELOPE.stp` is the corresponding Bourns body-envelope solid from the exact F.Fab
  extents and maximum body height.

Footprints, courtyards, holes, and fabrication data remain authoritative. These local solids are
mechanical review aids and must stay aligned with their footprint origins.

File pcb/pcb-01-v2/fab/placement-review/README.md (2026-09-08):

# PCBA placement and polarity review, 2026-09-07

## Verdict

The shown DFM for `SMT026083161536_Y8` passes the placement/polarity review. No correction is
required. Michael may confirm it to JLCPCB. No assembly approval or reply was submitted by the
agent. The authenticated order page now shows the PCB production file as **Confirmed**, while
assembly is Pending and awaiting the email response.

Review combined native KiCad pad extraction, the released orientation drawings, independent IC
and discrete-device checks, the emailed image, and the live DFM's component and package data.

## Retained evidence

- `jlc-dfm.png`: supplied 1778 x 1474 image; SHA-256
  `4e52a0c6db225b7a15c2d5958db3682f9cdc68ff9ffdd2808f33bb6ce737dfa1`.
- `factory-bom.zip`: live `Smt_Hw_Bom_Merge` download, containing the factory reference list,
  original coordinates, adjusted coordinates, rotation conventions, package UUIDs, and mount flags.
- `factory-preview.zip`: live `Smt_Hw_Web_File` download, containing the CAM preview geometry.
- `factory-packages.json`: the public package geometries requested by the live DFM viewer.
- `cpl-comparison.json`: full 119-reference comparison, including raw origin/rotation differences
  resolved below. Raw differences in this file are not unresolved placement failures.

Live DFM was opened from the order's **DFM Analysis** link. All 119 unique assembled designators
match `cpl-jlcpcb.csv` and the exact LCSC codes in `assembly-manifest.csv`. All are enabled on top;
there are zero bottom-side parts, missing references, or extra references. The original coordinates
and rotations retained by the factory match the submitted CPL exactly.

## Polarity and direction

Directions refer to the component-side image with J4 at the top.

| References | Required and shown orientation | Result |
| --- | --- | --- |
| U1 | Pin 1 northwest; white package dot northwest | Pass |
| U2 | Pin 1 northeast; antenna east toward board edge | Pass |
| U3, U4, U5, U6, U7, U9, U10, U11, U12 | Pin 1 northwest | Pass |
| U13 | Pin 1 southwest, USB_DP | Pass |
| U14 | Pin 1 northeast, USB_CC1 | Pass |
| D1, D3, D4, D5, D6, D7, D8 | Cathode band west | Pass |
| D2 | Cathode band south; anode north | Pass |
| D9 | Pin 1 northwest; lone lead east | Pass |
| Q1 | Gate/pin 1 southwest; drain tab north | Pass |
| Q2 | Gate/pin 1 northwest; lone drain lead east | Pass |
| Q3 | Gate/pin 1 southwest; lone drain lead north | Pass |
| J4 | Opening north toward board edge | Pass |
| RV1 | Pin 1 northeast; wiper south; screw southwest | Pass |
| SW1, SW2, SW3 | Contact rows and body align with horizontal pad pairs | Pass |

U13 and U14 intentionally face opposite directions, matching the dedicated released callout.
All factory-installed capacitors are nonpolar ceramic MLCCs; their pink dots are library pin
markers, not electrical polarity requirements. Resistors and L1 are nonpolar. The six hand-installed
references C1, C2, J1, J2, J3, U8 are correctly absent, as are DNP C44/C45.

## Coordinate differences resolved

Factory CAM coordinates use `x=x_CPL-50`, `y=y_CPL+119` in mm (CPL Y is negative). For 116 of 119
parts the adjusted placement reference lies within 0.01 mm of this transform. Three packages use
different reference origins; raw rotations also differ by library convention. Their geometry,
not matching raw angle numbers, determines correct placement:

- **U2:** raw adjusted X differs by -2.98465 mm. Transforming the actual factory package places
  all 28 perimeter pins within 0.01036 mm of their native pad centers, with antenna east. The
  package reference is near the electrical-pin/non-antenna center, rather than the entire module
  centroid. The factory model's nine inner ground squares differ from native lands by about
  0.2495 mm in Y; both are 0.8 mm squares with ground-contact overlap. This is a library-land
  difference, not evidence to shift the component away from its aligned perimeter pins.
- **U3:** raw adjusted Y differs by +0.57101 mm. All eleven transformed library pads map to
  their corresponding native lands. Land dimensions/centers differ by up to about 0.1002 mm;
  terminal-facing edges align (pad 2 inner X edge 84.649848 versus native 84.650 mm; pad 9 south
  Y edge 60.341516 versus native 60.350 mm). The factory body drawing also differs by about
  0.204 mm from native F.Fab artwork. These are drawing/reference differences, not the apparent
  0.571 mm whole-component shift.
- **J4:** raw adjusted Y differs by -1.20699 mm. Using the actual contact-metal polygons in
  `customData.pinsInfo[].weldingID`, all sixteen contacts fall inside their intended copper pads.
  Individual signal lead centers differ by at most 0.00022 mm in X and 0.00516 mm in Y. Shell
  stakes fit their slots and the model pegs fit nominal hole clearance. Mouth faces north. The
  library's recommended PAD centers are not identical to physical contact centers.

## Interpretation and sources

This confirms the intended assembly placement represented by this DFM and its part list. It does
not certify the eventual solder joints or actual reel markings. Some tiny model surfaces, notably
U3/U12, do not show a separately legible physical pin-1 mark; their DFM pin-1 markers and mapped
package geometry agree with the released design.

The discrete reviewer checked primary polarity/package drawings:
[MMSZ5242B](https://www.diodes.com/datasheet/download/MMSZ5242B.pdf),
[SMCJ24A](https://www.diodes.com/datasheet/download/SMCJ24A.pdf),
[Vishay BAT54W](https://www.vishay.com/docs/86409/bat54w-g.pdf),
[BAT54SLT1G](https://www.onsemi.com/pdf/datasheet/bat54slt1-d.pdf),
[DMP6023LE](https://www.diodes.com/datasheet/download/DMP6023LE.pdf),
[2N7002K](https://www.diodes.com/datasheet/download/2N7002K.pdf), and
[Bourns 3224](https://www.bourns.com/pdfs/3224.pdf).
Vishay BAT54W datasheet terminal numbering differs from KiCad's generic diode numbering; compare
the cathode band and electrical polarity, not those numbers directly.

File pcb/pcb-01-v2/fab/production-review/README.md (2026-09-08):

# Production-file review, 2026-09-07

Order `W2026083117295494`, PCB job `Y8-12177845A`, assembly `SMT026083161536-12177845A`.

## Evidence and findings

`2026-09-07-jlcpcb-production.zip` is the unmodified 4,462,522-byte authenticated download.
SHA-256: `8312b1b6e856da0d860cf55d4d4389c77a769aa38c311ff671a09dd33e2066e9`.
ZIP integrity passed. CAM Gerbers are in `ok/`; the ODB++ archive is `ok/12177845a_y8.tgz`.
These are returned factory evidence, not replacements for the released KiCad files or Gerbers.

- ODB++ `steps/edit/profile` is 88 x 64 mm. The `set` panel is 88 x 74 mm with 5 mm top/bottom
  process rails. Comparing submitted Gerbers with set CAM in mm requires
  `x_cam=x_submitted-50`, `y_cam=y_submitted+119` (submitted Gerber Y is negative).
- `misc/ImpedanceInfo` records all three approved width/edge-gap settings: `10.77/14.82 mil`,
  `12.87/38.30 mil`, and `12.87/46.18 mil`, each targeting 97 ohm on `tl/l2`.
- Parsed CAM `ts` and submitted `F_Mask.gts` confirm U3 pads 4/5 retain the 1.34 x 1.84 mm openings
  to Gerber rounding precision. Their board-local lower-left positions are `(33.630,50.055)` and
  `(36.030,50.055)` mm after removing the rail offset. Other nearby openings were enlarged by CAM;
  these protected apertures were preserved.
- Parsed CAM `drl` confirms all twelve 0.30 mm U1 pad 41 holes at the submitted CSV coordinates.
  Hole presence does not prove epoxy filling and copper capping. Inspected tools/metadata did not
  explicitly establish that treatment.

This was a targeted geometry/metadata check, not exhaustive copper/netlist equivalence, verification
of every compensated CAM trace width, or final assembly orientation review. The customer-facing
phrase "everything else looks good" must not be interpreted as proof those additional checks ran.
The separate Confirm Parts Placement gate remains outstanding.

## Submitted request

Michael reported submitting the confirmation/modification request on 2026-09-07. Prepared text:

> I have reviewed the production files and they look good. Before approving, I need confirmation
> that all twelve 0.30 mm holes inside U1 exposed pad 41 will be epoxy-filled and copper-capped
> (POFV), as specified in the previously submitted pofv-locations.csv and pofv-location-map.pdf.
>
> Please keep U1 pad 41's top solder-mask aperture open and add no bottom mask openings for these holes.
>
> This is the only outstanding item. If this treatment is already included, no modification is
> needed; please confirm it in writing.

`PCB-01-V2-POFV-support.zip` contains the existing PDF map and coordinate CSV from `fab/`.
A verified copy was supplied on Synology's `overflow` share for phone access. Actual attachment
upload was not independently verified. Michael mentioned a $2 cutting/remarks fee but asked to
disregard speculation about its purpose; the fee is not evidence of POFV treatment.

Await written confirmation, then compare any revised files with this archive and the release.
Do not repeat answered impedance questions unless the relevant geometry, stack, or copper changes.
No production approval was submitted by the agent.

## Download recovery

The first phone download was a 110-byte JSON error (`code:500`, `data:null`). The logged-in browser
download succeeded. **Confirm Production file** opens the review form; approval requires a separate
choice and Submit. Read the Download Production file anchor's actual href and fetch its bytes in
the authenticated page. Browser-control exposes `fs` and `Buffer` directly; `require` is unavailable.
Verify ZIP integrity before treating a download as production evidence.

## Factory confirmation received

Chian subsequently confirmed in writing that all twelve 0.30 mm via-in-pad holes inside U1
exposed pad 41 are filled with non-conductive epoxy and copper-capped; the top pad aperture remains
open and no bottom mask openings were added. Chian explicitly states that the treatment was
already included in the current production file. This clears the POFV process question; the
earlier review had not established the treatment, rather than proving it absent.

The accompanying [image](pofv-confirmation.png) identifies U1 and the correct 3 x 4 hole array,
with an arrow to the CAM `sk` layer. The written statement, not the screenshot alone, confirms
the fill/cap process. Michael may approve the reviewed PCB production file on this basis.
Actual approval has not yet been reported; assembly placement remains a separate later check.

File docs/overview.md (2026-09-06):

# Stillair overview

A quiet, low-profile 44-inch direct-drive ceiling fan for gentle overnight air mixing, with
local-only Apple Home control (Matter over Wi-Fi) and a minimal wood-and-white ceiling
presence. This repo is the
canonical source for the whole project: planning docs, BOM, firmware, CAD drawings,
authoritative tscircuit PCB source, and downstream KiCad boards. The full 3D model lives in
OnShape; everything else lives here.

## Key numbers

| Parameter | Value |
|---|---|
| Maximum rotor diameter | 44 in (1117.6 mm); 42 in fallback |
| Power bus | 24 V low-voltage, certified external supply |
| Target operating range | 35–170 RPM (minimum released only after qualification) |
| MCF driver speed limit | 180 RPM |
| Independent analog trip | 200 RPM nominal |
| Total ceiling drop | ≤10 in (254 mm absolute envelope) |
| Wall clearance | 5.5 in per side at 44 in diameter |
| Ceiling-to-blade gap | 8.0–8.2 in to nearest blade surface |
| Blades | Three symmetric 9 mm birch, 12° nominal pitch |
| Room | 55 in wide, 96 in ceiling, mattress top at 22 in; Vancouver, BC concrete condo |

## Architecture

Direct drive, low voltage, simple structure:

- **Motor**: CubeMars GL100 KV10 low-cogging gimbal motor (24 V, 20 pole pairs). Its KV10
  winding reaches the target speed with low phase current, giving the controller an easy
  low-speed operating point.
- **Drive**: TI MCF8316D sensorless FOC driver with integrated FETs, on a custom 78 × 58 mm
  four-layer controller PCB. The V1 board doubles as the development board (no TI evaluation
  module needed). V2 is only a contingency or optional later redesign; it may be smaller and does
  not inherit the V1 outline automatically. See [pcb-01-v2.md](pcb-01-v2.md).
- **Supervisor**: ESP32-C6-MINI-1-H4 running Matter over Wi-Fi (rs-matter, pure Rust), used
  from Apple Home. It configures the MCF over I²C and commands speed/direction; it never
  switches motor phases.
- **Power**: Mean Well GST60A24-P1J 24 V / 60 W certified supply, wall-side 3 A fuse and
  physical cutoff. Only low voltage crosses the ceiling.
- **Safety**: independent one-pulse Hall speed sensor → LM2907 → TLV1701 analog 200 RPM trip,
  hardware watchdog, and a permission latch that firmware can clear but not force. Mechanical
  backstops: a non-contact central rotor catcher and a separate rated whole-assembly tether.
- **Structure**: compact stainless ceiling plate, three aluminum standoffs, aluminum motor
  carrier and rotor hub, printed BP-100 blades, and a two-motion printed
  [housing](housing.md) with separate stationary and rotating sections.

## Design gates (dependency order)

1. **Motor system** (selected): GL100 KV10, MCF8316D FOC, 24 V / 60 W supply.
2. **Rotor geometry** (baseline set): 44 in, three birch blades, 12° nominal, 35–170 RPM target.
3. **Custom mechanics** (ready for CAD): dimensioned plan, elevation, section, hole, and
   tolerance views in [parts.md](parts.md).
4. **Build release** (qualification): V1 PCB, motor tuning, overspeed trip, bearings, and
   rotor proof. See [build.md](build.md).

## Scope

The design dossier (now these docs) defines the fan: dimensioned mechanical views, part
interfaces, materials, loads, exact standard components, a circuit-level PCB handoff,
placement zones, controller behavior, sources, and acceptance tests. What gets created from
it:

- Final 3D models in **OnShape** (not in this repo).
- Tscircuit schematic, board specification, and placement source in [`pcb/`](../pcb/), with KiCad
  owning downstream routing and production-only features.
- Firmware in [`firmware/`](../firmware/) (Rust, `no_std`, ESP32-C6).
- CNC/laser files for fabricated parts in [`cad/`](../cad/).

Slab verification and the local installation-approval path are site-specific execution work.

## Document map

- [decisions.md](decisions.md) — decision register: locked baseline, release gates, accepted deviations
- [mechanical.md](mechanical.md) — envelope, vertical stack, rotor geometry, retention
- [parts.md](parts.md) — dimensioned per-part specifications (the CAD handoff)
- [electrical.md](electrical.md) — PCB V1/V2 circuit and layout handoff
- [pcb-workflow.md](pcb-workflow.md): tscircuit source authority, KiCad handoff, and ECO rules
- [controls.md](controls.md) — motor-control contract and required state behavior
- [home-automation.md](home-automation.md) — provisional presence, comfort, and vacation behavior
- [observability.md](observability.md) — measurement authority, J8/scope hookups, synchronized evidence
- [probing.md](probing.md) — PCB-01 orientation, human test-point locations, connector pin views, and probe workflow
- [pcb-01-v2.md](pcb-01-v2.md) — conditional experience-based simplification and serviceability brief
- [motor-contingency.md](motor-contingency.md) — motor rejection criteria and least-disruption fallback paths
- [build.md](build.md) — build sequence, procurement gates, commissioning
- [integration.md](integration.md) — dependency spine, parallel tracks, and energy-sized next work
- [install.md](install.md) — anchors, slab verification, Vancouver approval path
- [../bom/bom.csv](../bom/bom.csv) — BOM with purchase tracking
- [../testing/test-matrix.csv](../testing/test-matrix.csv) — commissioning matrix with sign-off fields

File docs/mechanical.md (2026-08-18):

# Mechanical design

> **Temporary**: the original interactive envelope and stack diagrams are still viewable at
> https://stillair-fan-design.syas.chatgpt.site/mechanical (requires ChatGPT auth). Remove this
> link once the OnShape model reproduces them.

A fixed assembly with explicit motor gates. The GL100 structure is dimensioned part by part in
[parts.md](parts.md); this doc covers the envelope, the vertical stack, rotor geometry, and
the independent retention paths. Only purchased-motor measurements, slab conditions, and
qualification results remain release-dependent.

## Envelope

Baseline: 44 in diameter, 60 RPM typical operating point, ~4.5 in nearest-surface gap
(hugger regime — deliberate, see below), BP-100 twisted blade. 42 in remains the
airflow/handling fallback; 170 RPM is the user maximum.

| Parameter | Value |
|---|---|
| Rotor diameter | 43.94 in (Ø~1116; 44.0 in do-not-exceed) |
| Nearest-surface gap to ceiling | 4.68 in (118.8 mm) |
| Wall-tip clearance | 5.5 in / side |
| Tip speed (60 RPM) | 3.5 m/s |
| Blade pitch plane | 4.89 in (124.2 mm) down |
| Lowest blade surface | 5.87 in (149.2 mm) down — the assembly's lowest point |

**2026-07-27/28 raise**: the rotor was raised ~99 mm (blade bottom 248.5 → 149.2) so open
cabinet doors (~160 mm line) clear the blades — a hard collision constraint that arrived
after the original envelope was chosen. Realized as: standoffs 138 → **62** and the blade
adapter **deleted** (BP-100 v3 integrates the root, [blade-v2.md](blade-v2.md); the interim
84 mm/flat-BA-00 step lasted one day). Aero cost of the ~0.106 D ceiling gap and the RPM
compensation are recorded in [decisions.md](decisions.md) > Accepted deviations.

Wall-clearance deviation: 44 in leaves 5.5 in to each wall, below common 18-inch guidance. No
useful fan fits that guidance in this 55-inch space. Do not exceed 44 in, and keep 42 in
available if wall-flow testing is poor.

## Vertical stack

Z = 0 is the finished ceiling; positive Z points down. Everything stays inside 10 inches
(254 mm absolute). The 62 mm standoffs place the GL100 stationary face at Z76; its 34.2 mm
body ends at Z110.2, and the blade pitch plane is Z124.2 (the mid-thickness of the blade's
root rectangle, bolted flush to the hub underside). The blade tops (Z118.8) rise above the
root plane *beside* the mechanism — the rotor sweeps r ≥ ~96, outboard of every stationary
part below the plate, and the plate/housing sit well above. The spindle end (Z142, central,
r ≤ 11) is above the lowest blade surface, so the blades set the assembly's lowest point.

| Interface | Z, mm |
|---|---:|
| Ceiling and plate top | 0.0 |
| Ceiling plate underside | 6.0 |
| PCB envelope (horizontal under the plate; see [electrical.md](electrical.md)) | ~12–35 |
| Motor carrier top | 68.0 |
| Carrier underside / GL100 stationary face | 76.0 |
| GL100 rotating face | 110.2 |
| Rotor hub top / underside | 110.2 / 118.2 |
| Highest blade surface | 118.8 |
| Blade root rectangle (top flush on hub) | 118.2–130.2 |
| Catcher disk top / underside | 120.7 / 124.7 |
| Blade pitch plane (rod axis) | 124.2 |
| Castellated nut → cotter → spindle end | 124.7 → 137.2 → 142.0 |
| Lowest blade surface | 149.2 |
| Absolute lowest permitted point | 254.0 |

## Coordinate system

- Rotor axis: X0, Y0.
- Blade centerlines: 0°, 120°, 240°.
- Standoff centerlines: 90°, 210°, 330°.
- Tach stations: r76 on the three arm/blade-station lines, one per arm — one N52 magnet
  + two mass-matched brass slugs, balanced by three-fold symmetry (moved from
  r68 @ 30°/210° in the 2026-07-28 RH-100 spoke restyle). The stationary Hall sensor
  line stays 30°, sensing radius r76.
- Phase-lead window: r45.6 at 315° (clocked 2026-07-27 from the GL100 STEP: pad-to-bolt-hole
  offset is a fixed 44.43°, bolt holes on the axes, so the pad lands on ~45° diagonals; 315°
  keeps the Hall corridor at 30° clear and shortens the phase-lead run to the PCB side).

> **OnShape model frame**: the existing OnShape document is rotated **180° about Z** relative
> to this table (tether at +Y in the model, −Y here; lone standoff at −Y). Discovered
> 2026-07-27; kept as-is because the model is internally consistent. Convert with
> *model angle = doc angle + 180°*; Variable Studio angles (`#phaseClock`) are model-frame.

## Primary structure

Simple plates, posts, and one turned spindle (full dimensions in [parts.md](parts.md)):

- **MP-100 ceiling plate** — Ø210 × 6 mm 304 stainless. Two 11 × 20 mm anchor slots on 130 mm
  centers, three Ø6.6 standoff holes on Ø150 PCD, Ø16.2 spindle opening, separate tether
  opening, and a P-clip strain-relief tapping pair at 15° (no cable slot — the supply is a
  surface run entering at the housing rim; see [parts.md](parts.md) "Cable entry").
- **ST-100 standoffs** — three Ø16 × 62 mm 6061-T6 posts, M6 × 1 tapped ≥12 mm both ends
  (shortened from 138 in the 2026-07-27/28 raise).
- **MC-100 motor carrier** — Ø180 × 8 mm 6061-T6. Standoff holes on Ø150 PCD, 4 × Ø4.5 on the
  GL100 Ø60 PCD, Ø20.5 spindle clearance, tether pair, Hall mount, verified wire window.
- **RH-100 rotor hub** — Ø200 × 8 mm 6061-T6. Ø20.5 captured aperture, four
  underside-countersunk Ø4.5 holes on the GL100 Ø50 PCD for subflush M4 flat-heads, measured
  pilot ring, three dowel-registered blade-root stations (BP-100 v3 blades bolt directly,
  their printed pins engaging the dowel holes), retained tach magnet.

**Motor screw-depth rule**: rear M4 threads are officially 6 mm maximum; output-face M4
threads are 3.5 mm maximum. The baseline uses M4 × 12 through a 1.5 mm carrier counterbore
and M4 × 10 through the 8 mm hub. Both engagements must be physically measured before
machining release.

## Rotor geometry

> **Superseded 2026-07-27/28**: the rotor now uses printed BP-100 v3 cambered-airfoil
> blades with CF-rod spars, baked-in twist, and an **integrated root** bolted straight to
> the hub (no adapter at all) — see [blade-v2.md](blade-v2.md); pitch plane now Z124.2. The
> birch geometry below is retained as the fallback.

Three 9 mm birch blades on printed pitch adapters. Cut four, finish all four identically,
select the best-balanced three, keep the fourth as a ready spare. The symmetric edge treatment
supports reverse operation.

| Radius, mm | Chord, mm | Intent |
|---:|---:|---|
| 110 | 115 | Aerodynamic root and printed root stop |
| 180 | 122 | Inner load-spreader line |
| 320 | 132 | Maximum chord |
| 420 | 128 | Begin gradual taper |
| 500 | 108 | Tip transition |
| 558.8 | 92 | Exact 44-inch radius; R20 tip corners |

- **BA-10/12/14 adapters** — qualified CF-PPA, approx r52–205 with a y±25 hub base and wider
  blade saddle, printed flat on the hub base. Four M5 hub bolts plus two Ø5 dowels; four M5
  blade bolts at r135/r185 and y±25.
- **Metal load spreaders** — two 65 × 15 × 2 mm 6061 straps per blade, each bridging a 50 mm
  tangential bolt pair on the upper face. No printed thread or heat-set insert carries the
  primary load.

## Independent retention

Two secondary load paths:

1. **Central catcher** (SP-100 + KD-100) protects against GL100 bearing/rotor retention
   failure and four-M4 hub release. 17-4PH Ø16 flanged spindle with a Z120.7 shoulder, M12
   lower thread, Ø44 × 4 mm DIN 440 A4 catcher washer (2026-07-28: a purchased Accu part
   replaced the custom Ø50 × 4 laser disk — see [parts.md](parts.md) KD-100), castellated
   nut, and cotter. The flange carries
   two 30.0 mm across-flats keyed into a matching double-D pocket in MP-100, so the nut
   torques from below with no counter-hold. The spindle passes
   through the GL100 Ø30 bore without normal contact (Ø20.5 hub aperture gives 2.25 mm radial
   gap per side; 2.5 ±0.5 mm axial gap to the disk). The M4 hub screws are 0.1–0.2 mm
   subflush; verify ≥2.0 mm worst-case clearance to every rotating surface. Static proof to
   1.25 kN, then dynamically catch the final mass off-ceiling, including an off-axis/tilted
   drop case (pure-axial is the optimistic assumption).
2. **Whole-assembly tether** protects against the plate, standoffs, and primary anchors as a
   group. At least 4.5 kN complete-system rating, 15–20 mm slack, separate concrete anchor,
   and a rated two-hole fitting at MC-100. Calculate impact energy and dynamically catch the
   final assembly on a representative fixture.

## Motor release gates

Measure these before ordering motor-dependent metal:

- **Face ownership** — confirm Ø50/M4 rotates and Ø60/M4 is stationary.
- **Bore + pilot** — measure both bore faces and identify which surfaces rotate.
- **Thread depth** — depth-pin both M4 patterns before selecting final screws.
- **Wire exit** — import the current STEP and locate the rear lead window and flat annuli.
- **Bearing load** — obtain axial/radial/inertia basis or accept it as documented residual risk.

## Proof and quality targets

| Item | Value |
|---|---|
| Runaway load case | 270 RPM (calculation basis, raised from 250 in 2026-07 review — supply-power bound; never dynamically tested) |
| Workshop rotor proof | 216 RPM × 2 min/direction on a secured external drive, continuously observed |
| Installed blade-root joint proof | 500 N radial each (was "adapter proof"; the printed root joint inherits it) |
| Batch destructive test | >1.0 kN |
| Hub OD runout | ≤0.10 mm TIR |
| Blade first-moment mismatch | ≤0.5% |

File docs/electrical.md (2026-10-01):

# PCB handoff (PCB-01 V1 controller)

> **Temporary**: the original schematic-block and placement-zone diagrams are still viewable at
> https://stillair-fan-design.syas.chatgpt.site/electrical (requires ChatGPT auth). Remove this
> link once the KiCad schematic is captured.

Defines the V1 controller board for the CubeMars GL100 KV10. V2 is specified separately in
[`pcb-01-v2.md`](pcb-01-v2.md); that document controls every V2 component, interface, net, board
rule, and validation delta. This is the V1 circuit and layout record: capture and peer-review in
[`pcb/`](../pcb/) (KiCad), verify footprints, run ERC/DRC, and compare the MCF power stage
directly with TI's reference layout.

## Architecture

```text
GST60A24-P1J, 24 V / 2.5 A / 60 W
  -> 3 A source fuse -> physical cutoff -> 18/2 feed
  -> reverse PMOS -> SMCJ24A -> 2 x 470 uF / 50 V
       +-> MCF8316D -> GL100 phases U/V/W
       +-> TPSM365R6V3 -> 3.3 V -> ESP32-C6 + latch + watchdog + comparator
       +-> TPS7A1601A -> 12.049 V -> LM2907 analog tach

Rotor magnet -> DRV5033 -> LM2907 -> TLV1701
             -> hardware permission latch /CLR -> DRVOFF
```

The custom V1 board replaces the TI evaluation module. V1 is deliberately roomy and
instrumented (full USB, direct I²C, scope header, test pads, rework links, manual
clear/DRVOFF controls). Those choices remain the as-built V1 record, not V2 requirements.

## PCB-01 V1 mechanical definition

- Outline: 78.0 × 58.0 mm, R3 corners.
- Construction: four-layer FR-4, 1.6 mm.
- Copper: 2 oz outer, 1 oz inner.
- Finish: ENIG.
- Mounting: four Ø3.2 mm NPTH at (6,6), (72,6), (6,52), (72,52) mm from the lower-left
  (66 × 46 mm hole rectangle). Keep all copper and components outside an Ø8 mm circle around
  each hole; use 6–8 mm M3 standoffs and leave the holes isolated from circuit ground.
- V2 does not inherit this outline, hole pattern, or the abandoned annular-board option. Its
  rectangular outline and four M3 hole coordinates follow V2 placement as specified in
  [`pcb-01-v2.md`](pcb-01-v2.md).

**Fabrication** (decided 2026-07-30): JLCPCB fabricates AND assembles. Board options:
4-layer JLC04161H-7628 stackup, 1.6 mm, 2 oz outer / 1 oz inner, ENIG, **Standard PCBA**
(forced — the ESP32-C6-MINI-1 is a JLCPCB "Standard Only" part), single-side (all SMD is
top-side), min 5 boards / 2 assembled. Request POFV (epoxy filled & capped) via covering
for the MCF thermal cluster. The package is generated headless by
`python3 pcb/tools/jlc_fab.py` → `pcb/pcb-01/fab/` (gerber zip, BOM, CPL); LCSC numbers
for parts whose schematic LCSC field is empty live in `pcb/pcb-01/fab/lcsc-map.csv` with
per-line substitution rationale (owner-approved 2026-07-30: 1% resistors where 0.1%
is unstocked — RV1 end-to-end calibration absorbs initial tolerance; X5R for X7R on
bypass lines; Vishay BAT54W-G3-08 for the dead-stock Nexperia BAT54H).

**Hand-populated at the bench** (excluded from the assembly files by `jlc_fab.py`):
C1/C2 (Panasonic FR authenticity — DigiKey stock in hand), J1/J2 (Molex Micro-Fit in
hand), U8 (LM2907 dead on LCSC; DigiKey qty 3 in hand), and C34 — the LM2907
charge-pump timing cap must stay C0G/U2J for overspeed-chain temperature stability and
no 0603 C0G 100 nF exists at JLCPCB in any tolerance. **2026-07-30 sourcing sweep
finding: a 0603 (or 0805) class-1 100 nF does not exist from any manufacturer — it's a
dielectric-permittivity limit, not a stock gap** (this section's earlier TDK
C1608C0G1E104J example was a phantom part number; the smallest real class-1 100 nF is
1206). **Decision (locked 2026-07-30): KEMET C1206C104K3GACTU** (1206, C0G, 25 V,
±10 % — RV1's trim range absorbs the tolerance; 562k + 0–200k covers a ±10 % C34 with
headroom), **hand-bridged onto C34's 0603 site**: a 1206's termination inner edges
(±1.1 mm) overlap a 0603 footprint's pad outer edges (±1.2 mm), so it sits on the site
with generous fillets — standard upsize rework, inspectable, verified functionally by
TACH-01 calibration. Rationale: X7R would age −2..−5 %/year after calibration, drifting
the trip *upward* (the safety-eroding direction) unwatched; C0G ends that permanently.
An X7R 0603 drop-in from the PCB-02 decoupling strip stays on the bench as the
fast-bring-up fallback only; if a V2 board happens, C34's footprint becomes 1206. J3/J4
(JST PH THT) ride JLCPCB's hand-solder service instead, since genuine JST is
deep-stocked there. Bench work on arrival also includes **bridging F1's pads** (DNP
1206 fuse footprint; the real fuse is the wall-box ATO).

## SCH-01 24 V input

Source chain:

```text
GST60A24-P1J -> Switchcraft 721A -> 3 A ATO fuse
-> 5 A / 28 VDC cutoff -> Belden 5300UE 18/2 -> J1
```

The 18 AWG feed is good for a total source-to-board run of at most 20 ft (published 6.5
Ω/1000 ft gives about 0.65 V round-trip drop at 2.5 A over 20 ft). For a longer run, retain
16 AWG in the conduit and transition to short 18 AWG pigtails with a listed, insulated splice
before the Micro-Fit contacts.

Reverse-polarity protection with `DMP6023LE-13` (−60 V P-channel MOSFET):

- **Drain to `RAW24`, source to `VM24`** — the dossier's original orientation, which is the
  canonical P-FET reverse-protection circuit (TI SLVA139 class). Review history: a first
  review pass "corrected" this to source-at-input, claiming body-diode inrush stress; an
  adversarial verification pass then proved that swap wrong and it was reverted. In the
  correct orientation the body diode conducts only for the sub-millisecond until the cap
  bank reaches ~3 V and the channel enhances (charge through the diode ≈ 3 mC, far inside
  surge ratings), and under reverse polarity the diode blocks. In the swapped orientation
  reverse current flows freely through the body diode — no protection at all. Do not
  "fix" this again.
- Gate to AGND through 10 kΩ; gate to source through 100 kΩ.
- `MMSZ5242B` 12 V zener, cathode at source and anode at gate. The zener is load-bearing,
  not optional: without it the divider drives Vgs to ≈ −22 V, past the ±20 V absolute
  maximum.

On `VM24`:

- `SMCJ24A`, cathode to VM24 and anode to PGND.
- 2 × Panasonic `EEU-FR1H471`, 470 µF / 50 V low-ESR bulk (940 µF total).
- 2 × 10 µF / 50 V X7R plus 100 nF / 50 V immediately beside the MCF VM/PGND current loop.

TVS standoff note (2026-07 review): the GST60A24's tolerance is ±3%, so worst-case
continuous output (24.72 V) slightly exceeds the SMCJ24A's 24 V standoff rating. This is
**accepted deliberately**: minimum breakdown (~26.7 V) still clears it, and the "fix"
(SMCJ26A) raises the maximum clamp to ~42 V — above the MCF's 40 V ceiling, which is the
margin that actually matters. Fuse note: the ordered 3 A fast-blow has ~10× I²t margin
against inrush at the full 20 ft cable run but shrinks toward ~1.4× on a short bench run;
if bench nuisance-blows occur, substitute a 3 A time-delay fuse rather than uprating.

**Mandatory V1 scope gate**: the SMCJ24A maximum published clamp is 38.9 V, only 1.1 V below
the MCF8316D's 40 V absolute maximum. V1 must scope VM during insertion, cutoff, coast, stall
release, and reversal with the final cable and rotor. Normal transient target is ≤35 V; any
observed excursion to 40 V rejects the design and requires revised energy management.

**Energy rule**: the TVS is not a rotor brake. Enable MCF AVS, use 1–3 RPM/s deceleration,
coast by default, and never reverse until the rotor is stopped.

The source supply is 60 W. A 90 W brick is only a fallback if measured startup or transient
behavior shows the GST60 is inadequate.

## SCH-02 3.3 V logic rail

`TPSM365R6V3RDNR`, fixed 3.3 V / 600 mA, 65 V input:

- Input: 2.2 µF / 100 V X7R plus 100 nF / 100 V.
- Output: 2 × 22 µF X7R, **16–25 V rated in 1206/1210** — the datasheet floor is 40 µF
  *effective*, and small-case 10 V parts derate below it at 3.3 V DC bias (TI's own BOM uses
  25 V 1210).
- CVCC: 1 µF / 16 V. BIAS: directly to the 3.3 V output.
- **EN: tie to VM24** (or a UVLO divider) — the datasheet forbids floating it.
- PGOOD: 10 kΩ pull-up to **VCC (pin 8, `U3_VCC`)**, routed into the permission-clear path.
  (2026-07 board review: TI documents VCC — the internal LDO, independent of the switched
  output — as the intended PGOOD pull-up source; pulling up from VOUT makes the flag's own
  reference collapse together with the fault it reports.)
- MODE/SYNC selection via a 3-pad jumper to GND (auto/PFM, default) or 3.3 V (forced PWM) —
  the pin must never float; an unpopulated 2-pad jumper is an invalid state.
- Power budget (verified 2026-07): worst-case simultaneous 3.3 V load ≈ 391 mA (Wi-Fi TX
  peak 382 mA dominates; BLE/Wi-Fi coex time-multiplexes and does not add) vs 600 mA rating
  — adequate with ~35% headroom. J5/J7 export 3.3 V to bench tools; the headroom covers
  typical probes.

Do not substitute a 36 V-rated regulator behind a TVS that may clamp near 39 V.

## SCH-03 MCF8316D power stage

`MCF8316DVRGFR`; follow TI's pinout and reference-layout loop geometry literally.

Variant note (researched 2026-07): swapped from `MCF8316DULVRGFR`. Datasheet Table 4-1 shows
the only differences are the UL 60730-1 recognition and an on-die Self Test Library (STL
command/status bits) that requires MCU-driven BIST to mean anything; silicon, pinout,
register map, and motor control are identical. This design's safety case is the external
hardware chain, and the plain D is LCSC-stocked for JLCPCB assembly. Capture with the
**D-generation pinout** — pins 36–39 (DACOUT1/DACOUT2/SOX/ALARM) differ from the A1, and the
D register map differs from A1/C (use TI's C→D conversion tool mindset; never reuse A1
register dumps or community drivers untranslated).

- VM pins 9–11 to VM24. OUTA 13/14 → U, OUTB 16/17 → V, OUTC 19/20 → W.
- PGND pins 12/15/18 joined locally. Exposed pad to AGND with a dense thermal-via array
  (≥12 vias).

| Connection | Starting value | Purpose |
|---|---|---|
| CP → VM | 1 µF, 16 V X7R | Charge-pump reservoir |
| CPH ↔ CPL | 47 nF, **100 V** X7R | Flying capacitor (datasheet wants ≥2× VM; 50 V gave only 4% margin at nominal bus) |
| AVDD → AGND | 1 µF, 10 V X7R | Analog rail bypass |
| DVDD → DGND | 1 µF, ≥6.3 V X7R | Digital rail bypass |
| SW_BK → FB_BK | 47 µH Sunlord SWPA6045S470MT | MCF auxiliary buck. Isat gate (≥ 910 mA buck OCP max) resolved at capture 2026-07-28: the whole LPS4018/SWPA4018 4 mm class sits at ~0.55 A and fails, and LPS5030 (0.53 A) does not close the gap either — the family step buys Irms, not saturation margin (no 47 µH XAL40xx exists). SWPA6045 is 1.4 A Isat, shielded, LCSC-stocked; DigiKey alternate LPS6225-473MRB (1.0 A). The rail is near-unloaded, so the gate protects the startup-inrush and shorted-scope-header corners where a saturated inductor defeats cycle-by-cycle OCP — cheap margin, and it keeps the fault-matrix buck-OCP row interpretable |
| FB_BK → GND_BK | 22 µF, 10 V X7R | Buck output |
| FG, nFAULT | 4.7 kΩ pull-ups to 3.3 V | Open-drain outputs |
| SDA, SCL | 4.7 kΩ pull-ups to 3.3 V | Configuration bus |

### GL100 commissioning seeds

CubeMars publishes 2.650 Ω line-to-line resistance and 2.350 mH inductance for the star
motor: begin with phase-neutral 1.325 Ω and 1.175 mH. Full register seeds and the
measured-data gate live in [controls.md](controls.md). FG cannot be divided to exactly one
pulse per revolution for 20 pole pairs. **Configure FG_DIV = 1h (divide-by-1): 20
pulses/revolution**, 11.7 Hz at 35 RPM — FG is contract-critical for stop verification and
the FG-vs-Hall plausibility check, and /1 gives an order of magnitude better supervisory
resolution and latency than the previously suggested /10. FG is not the independent
overspeed channel.

I²C note: the MCF is not a plain SMBus device — every transaction starts with a 24-bit
control word (R/W, CRC enable, data length, memory section/page/address). No factory-default
7-bit target address is explicitly stated in the datasheet (examples use 0x60); bus-scan at
first bring-up rather than assuming.

## SCH-04 ESP32-C6 supervisor

`ESP32-C6-MINI-1-H4` (4 MB in-package flash, −40 to 105 °C; preferred over the
normal-temperature N4 variant). Supervision and the Matter bridge stay separate from
commutation: the
ESP configures the MCF through I²C and sends speed/direction commands; it never switches
motor phases.

- 22 µF + 100 nF at 3.3 V (bumped from 10 µF to match Espressif's reference design; Wi-Fi
  TX bursts peak ~382 mA).
- 10 kΩ + 1 µF on EN; reset and boot buttons.
- 100 Ω series on SPEED, DIR, ARM_PULSE, and the watchdog heartbeat.
- DNP isolation links on I²C.
- USB-C native D−/D+ through 22 Ω, `TPD2EUSB30` ESD (**DRT 3-pin SOT package — footprint
  `Texas_DRT-3`**; the part does not exist in SOT-563, corrected 2026-07), 5.1 kΩ on
  CC1/CC2. VBUS is sense/test
  only and never powers the fan.

GPIO map, verified against the ESP32-C6-MINI-1 datasheet v1.5 (2026-07): every pin below is
exposed on the module (the MINI-1 exposes GPIO0–9 and 12–23) and none is a strap pin. The C6
straps are GPIO4, 5, 8, 9, and 15 — keep them free of unreviewed pulls. The original plan's
GPIO14 NTC input was wrong (C6 ADC1 lives only on GPIO0–6; GPIO14 has no ADC), so the NTC
moved to GPIO6 — a non-strap pin whose JTAG-default function (MTCK) is inactive unless
deliberately re-fused.

| GPIO | Signal | Note |
|---|---|---|
| 0 / 1 | SDA / SCL | MCF configuration bus |
| 2 | SPEED PWM | 1 kHz carrier; MCF normal 325 Hz–100 kHz input band |
| 3 | DIR | |
| 6 | NTC ADC | optional temperature; ADC1_CH6 |
| 7 | HALL_TACH sense | 3.3 V-domain Hall input for the FG-vs-Hall plausibility check (added 2026-07 review — the check was unimplementable without it); non-strap, JTAG-inactive by default |
| 12 / 13 | USB D− / D+ | native USB (fixed-function pins) |
| 14 | MCF ALARM | push-pull active-high fault companion to nFAULT |
| 15 | MCU_CLEAR_N | open-drain out, 10 kΩ pull-up (added 2026-07 review — it had no pin). Strap reviewed: GPIO15's JTAG-select strap is ignored with default eFuses, and the pull-up satisfies "don't float" |
| 16 / 17 | UART TX / RX | U0TXD / U0RXD defaults |
| 18 | permission ARM_PULSE | hardware safety handshake; software-sequenced pulse only |
| 19 | watchdog heartbeat | hardware safety handshake; bit-banged only (see controls.md) |
| 20 | MCF FG | FG_DIV = 1h, 20 pulses/rev |
| 21 | MCF nFAULT | diagnostic |
| 22 | 3.3 V PGOOD | diagnostic |
| 23 | watchdog WDO | diagnostic |

Boot-strap hardware (2026-07 review): add a **10 kΩ pull-up to 3.3 V on GPIO8** — download
boot requires GPIO8 = 1 while GPIO9 = 0, GPIO8 floats with no internal pull, and Espressif's
own reference design adds this resistor; without it, flashing via J7 is unreliable. Add an
external 10 kΩ pull-up on GPIO9 as well (the internal ~45 kΩ is weak for a motor board with
an exposed header). Layout note: GPIO18 (ARM_PULSE) and GPIO19 (heartbeat) are adjacent —
a solder bridge turns the heartbeat into an automatic re-arm clock; separate them in layout
or route with care.

NTC circuit (was unspecified): 10 kΩ 1% from 3.3 V to GPIO6, 10 kΩ NTC from GPIO6 to AGND,
100 nF at the pin (Espressif's ADC filter recommendation), ADC at 11 dB attenuation
(0–3300 mV, ±40 mV). Sensor element selected 2026-07-30 (the J4 cable had every part
purchased except the sensor itself — swarm finding): **Vishay NTCALUG01T103G501**, 10 kΩ
25 °C, B=3984 K ±0.5 %, ring-lug terminal that bolts to the GL100 housing; qty 1 ordered in
DigiKey 100888768. Exact stationary mounting point is TBD with the final housing-integrated
Hall mount; firmware read remains TODO(temp-sense). VBUS sense divider (was unspecified):
100 kΩ / 100 kΩ to a test pad or ADC pin — 5.25 V max lands at 2.6 V, inside the 3.3 V limit.

Two module caveats: ADC range/accuracy specs apply only to chips manufactured on/after
shielding-case date code **212023** or modules assembled on/after bar-code D/C **2321**
(corrected 2026-07 — the earlier "PW-2023-06" format was a dossier fabrication; check the
real date code before trusting NTC accuracy). And only GPIO0–7 have LP aliases, so
deep-sleep wake sources, if ever wanted, must come from that range (the NTC on 6, HALL on 7,
and I²C on 0/1 qualify; GPIO18–23 cannot wake). J7 programming note: there is deliberately
no on-board auto-reset network — the TC2030 jig must drive EN and BOOT (GPIO9) directly.

## SCH-05 hardware permission and watchdog

Firmware can enable the bridge; it cannot keep it enabled after a fault.

U5 permission latch, `SN74LVC1G74DCTR`:

- VCC 3.3 V; D to 3.3 V; **`/PRE` tied directly to VCC** (2026-07 review: through a
  resistor, an open pull-up leaves `/PRE` floating and a subsequent fault's both-asserted
  state would force Q *high* — the fault would enable drive).
- CLK from ESP ARM_PULSE through 100 Ω with 100 kΩ pulldown.
- `/CLR` 10 kΩ pull-up, **no capacitor** (2026-07 review: the previous 100 nF gave
  millisecond edges, ~5 orders outside the LVC1G74's 10 ns/V input transition-rate spec — a
  metastability window on safety logic). Buffer `/CLR` through an `SN74LVC1G17` Schmitt
  gate so the slow diode-OR node presents a clean edge.
- Q through 1 kΩ to a `2N7002K` gate with 100 kΩ gate-source pulldown; MOSFET source to AGND,
  drain to MCF DRVOFF; DRVOFF 4.7 kΩ pull-up to MCF AVDD.
- Feed 3.3 V PGOOD, TPS3435 WDO, `OS_LOCK_OK`, `MCU_CLEAR_N`, and the manual-clear button
  into the `/CLR` wired-OR node through individual BAT54H diodes — anodes at the wired-OR
  node (which feeds the `SN74LVC1G17` buffer, not the `/CLR` pin directly), cathodes at
  each active-low source. Six BAT54H total including U6's `/PRE` discharge diode.
  `MCU_CLEAR_N` is an ESP open-drain output with 10 kΩ pull-up: firmware can revoke
  permission but cannot override any fault.
- U6's own `/CLR` node (the OVERSPEED_N / TACH_PGOOD_N wire-OR) is deliberately
  **unbuffered** despite its slow ~µs edges: U6's CLK is tied low, so the clock-vs-async
  race that motivates the U5 Schmitt cannot occur, and slow-edge glitching on an async
  clear only re-asserts the state it is already entering. Documented waiver, not an
  oversight.

U6 persistent safety lock, second `SN74LVC1G74DCTR`:

- VCC 3.3 V; D high; CLK low.
- **`/PRE` from *delayed* PGOOD** — a 2026-07 review fix for a confirmed dead-on-arrival
  race (found independently by four reviewers): as originally drawn (`/PRE` from raw
  PGOOD), PGOOD releases ~5.5 ms after the 3.3 V rail while `TACH_PGOOD_N` on `/CLR` stays
  asserted for the TPS7A16's deliberate 60–120 ms DELAY, so `/PRE` released first, the
  '1G74 latched Q low, and with CLK grounded nothing could ever set it again — the fan
  could never arm, and every power cycle replayed the race. Fix: PGOOD → RC (**100 kΩ
  pull-up, 10 µF** — the values matter; a first-pass 10 kΩ/22 µF could only deliver
  ~115–195 ms against the Schmitt VT+ corners and did not close the race at datasheet
  corners) → `SN74LVC1G17` Schmitt buffer → `/PRE`, with a discharge diode (anode at the RC
  node, cathode at PGOOD) so power-down re-asserts preset promptly. Corner math: charging
  from the ~0.35 V clamp, delay = 0.55–1.1 s across the LVC1G17 VT+ range (1.6–2.1 V) —
  dwarfed by the 10 s safe boot. On the other side, **reduce the TPS7A16 DELAY cap from
  100 nF to 10 nF** (~12 ms typical): its I_DELAY spec has no minimum, so the slow corner
  is formally unbounded, and margin comes from the ~50× ratio rather than a bounded
  worst case. PCB-03D still tests the ordering on real hardware.
- Glitch behavior, stated honestly (a first-pass claim of ~300 ms glitch immunity was
  wrong): `/PRE` *asserts* at the start of a PGOOD dip via the discharge diode — the RC
  delays release, not assertion — so any dip longer than the ~ms diode-discharge time
  presets U6 healthy. Prompt power-down assert and long glitch immunity are mutually
  exclusive in this topology. Accepted because a PGOOD dip also clears U5 through its own
  diode and a fresh user command plus the 10 s hold are still required before any restart;
  the residual (a mid-coast brownout erasing the overspeed latch after the rotor has slowed)
  is documented rather than defended.
- `/CLR` receives `OVERSPEED_N` and `TACH_PGOOD_N` as active-low wired fault sources (both
  verified open-collector/open-drain, so the direct wire-OR is valid; no diodes needed).
- Q is `OS_LOCK_OK` and clears U5 when low.
- There is no firmware or network-side reset path to U6. After overspeed or tach-rail loss,
  only a genuine power cycle (long enough to discharge the `/PRE` RC) presets it healthy
  again, and U5 still requires a fresh user command afterward. During a simultaneous
  overspeed + brownout both async inputs assert (a nonstable '1G74 state); safety holds
  because PGOOD independently clears U5 through its own diode.

Do not connect MCF nFAULT directly to asynchronous `/CLR` until its DRVOFF/startup
interaction is characterized. Keep it diagnostic and configure every configurable motor fault
to latched Hi-Z. V1 must run a fault-by-fault matrix (FET thermal recovery, buck thermal/OCP
reset, phase loss, lock, overcurrent, undervoltage); any condition that can re-energize the
motor without a new command is a V2 blocker and requires a dedicated persistent hardware
fault-lock input.

Watchdog: `TPS3435CAKAGDDFR`, fixed-time **pinout C** in SOT-23-8 (not pin- or
footprint-compatible with TPS3431; capture by exact orderable part number):

| Pin | Name | Connection |
|---:|---|---|
| 1 | SET0 | 10 kΩ to GND (1× timeout) |
| 2 | MR | 10 kΩ to 3.3 V; test pad only |
| 3 | WDI | 2 Hz, 50% duty ESP heartbeat through 100 Ω; service is the falling edge |
| 4 | GND | AGND |
| 5 | SET1 | 10 kΩ to GND (1× timeout) |
| 6 | WD-EN | 10 kΩ to 3.3 V so firmware cannot disable the watchdog |
| 7 | WDO | 10 kΩ pull-up to 3.3 V, then BAT54H into U5 `/CLR`; also to GPIO23 |
| 8 | VDD | 3.3 V with 100 nF local bypass |

With SET[1:0] = 00 the timeout is 1.6 s nominal ±10%. The device has no startup delay and
begins monitoring immediately; early WDO pulses before firmware boots are safe because U5
already powers up cleared and firmware cannot arm until its heartbeat is running. WDO is
active-low open-drain and asserts for 200 ms after a timeout; U5 converts that pulse into a
held-off motor state. WDO clears motor permission but does not reset the ESP.

Wire the same 2 Hz heartbeat into the MCF's **EXT_WD input (pin 32)** through a separate
100 Ω resistor — a second zero-extra-parts "MCU died → motor Hi-Z" path inside the driver
itself. Required registers (2026-07 review; without these the path silently doesn't exist):
`EXT_WDT_EN` = 1, input mode = pin, **`EXT_WDT_CONFIG` = 1000 ms** (the tickle is the
rising edge every 500 ms, so 500 ms is zero-margin and 100/200 ms fault instantly), and
**`EXT_WDT_FAULT_MODE` = 1b** = latched Hi-Z — note this field's encoding is *inverted*
relative to the other fault modes (0b = report-only). Test both watchdog consumers
independently; do not merge their inputs after the resistors.

Residual risks in the permission chain, documented deliberately (2026-07 review):

- **WDO is a 200 ms pulse, not a latch**: pathological-but-alive firmware could re-arm 200 ms
  after every watchdog trip (run/coast oscillation). Mitigated by the MCF EXT_WDT latched
  Hi-Z (above) catching a truly stopped heartbeat, and by the firmware rules in controls.md
  (bit-banged heartbeat, software-sequenced ARM_PULSE).
- **Single-point failures that force drive enabled**: a drain-source-shorted 2N7002K (or a
  DRVOFF-to-GND solder defect) holds DRVOFF low regardless of every latch; an open DRVOFF
  pull-up leaves an undefined CMOS input; an open BAT54H silently disconnects one fault
  source from `/CLR` (latent until demanded). Accepted as residual risk — the remaining
  cover is the MCF's internal limits — with per-path verification rows in the test matrix.
- Diode-OR low-level margin: worst-case source VOL + BAT54H VF stacks to ~0.6–0.75 V
  against VIL 0.8 V; real currents sit near 0.4–0.5 V. Thin on paper, fine in practice;
  re-check at temperature extremes during V1.

Also route the MCF's **ALARM output (pin 39** — push-pull, active-high, enabled via
ALARM_PIN_EN**)** to the spare ESP GPIO14: it is an opposite-polarity companion to the
open-drain nFAULT, so a stuck-low nFAULT line can't silently hide faults. Diagnostic only,
like nFAULT.

One IPD caveat for the fault matrix: if IPD startup (MTR_STARTUP = 10b) is used to avoid
align reverse-kick, IPD faults are hard-wired retry (not latchable) — a failed *start
attempt* re-attempts. This is distinct from a running-fault auto-restart; document it as
accepted behavior or use align startup if even that is unacceptable.

Firmware may arm only after all fault sources are healthy, configuration is complete, the
requested speed is zero, watchdog service is live, and DRVOFF has remained high for at least
10 seconds.

## SCH-06 independent Hall tach

One physical revolution becomes one analog safety decision. A single captive magnet avoids
the dangerous half-speed failure mode of a two-magnet tach; an equal-mass nonmagnetic slug at
180° restores balance.

Hall daughterboard (**PCB-02**, 24 × 8 mm — grown from the original 18 × 8 at 2026-07-30
capture: the side-entry JST courtyard plus two M2 holes don't fit in 18 mm; KiCad project
`pcb/pcb-02/`, 2-layer 1 oz):

- `DRV5033FAQDBZR`, 3.3 V, 100 nF local bypass, open-drain output with 10 kΩ pull-up on the
  main board.
- J1 **S3B-PH-K-S** (JST-PH side entry, settled 2026-07-30): 1 = 3V3, 2 = HALL_TACH,
  3 = AGND — mirrors J3 on PCB-01. Cable exits in the board plane away from the hub.
- Owner confirmation (Michael, procurement reconciliation conversation, 2026-09-30
  America/Vancouver): the PCB-01 J3 to PCB-02 J1 Hall sensor harness is built and done.
  This completion report adds no new electrical test or commissioning evidence and is
  separate from CrystalShim's external sensor cable.
- Verified harness colors (2026-08-19): with PCB-01 viewed component-side and C1/C2 at the
  upper left, J3 is red/blue/green from left to right (3V3/HALL_TACH/AGND). With PCB-02
  viewed component-side and J1 at the top, the same straight-through harness appears
  green/blue/red from top to bottom (AGND/HALL_TACH/3V3). The board-view frames are mirrored;
  the electrical cable remains contact 1-to-1, 2-to-2, and 3-to-3.
- All components on the magnet-facing side (single-sided hand assembly); the sensor face is
  the closest surface to the magnet cap.
- Mounting: two Ø2.2 mm NPTH (M2) on the board centerline at board-local (7, 4) and
  (13, 4) mm — 6 mm pitch (H2 moved from 14 at placement: the S3B courtyard extends
  1.85 mm behind its pad row, and at 14 an M2 washer would touch the connector body).
  These are the BR-100 bracket datum; U1's sensor element sits at the inner end (r76
  line) at board-local (2.5, 4), J1's body flush at the outer edge.
- Sensor element and captive Ø6.35 × 3.18 mm (1/4 × 1/8 in) N52 magnet both at r76.0 ±0.5 mm (moved with the
  RH-100 tach stations 2026-07-28); south pole toward the
  package by convention (the FA variant is omnipolar — TI datasheet §7.1 — so a reversed
  magnet still trips at the same threshold magnitudes; polarity is not assembly-critical);
  magnet face parallel to the Hall PCB. The element sits at U1's placed anchor,
  board-local (2.5, 4): 4.5 mm from H1 along the hole centerline, zero cross-axis offset
  (2026-07-30 review, verified from TI §11.1.2 + the footprint file).
- Axial gap 2.5 mm nominal, adjustable 1.5–4.0 mm, **measured from the SOT-23's marked
  outer face (the surface toward the magnet) to the magnet cap**. The Hall element sits
  ≈0.4 mm behind that face (TI §11.1.2: 0.7 mm above the seating plane in a 1.12 mm
  package), so element-to-magnet is gap + 0.4 mm; the 15× field margin absorbs it, but
  record measurements against the package face, never the PCB substrate (measuring from
  the substrate would under-report the true clearance by the package height).
- Bench verification with the intended rotor magnet (2026-08-19): HALL_TACH measured
  3.251 V released and 0.04 V active, with a repeatable digital transition at about 10 mm.
  Firmware telemetry counted repeated approaches and releases. The sharp transition is the
  expected switch behavior, not an analog distance output.
- Considered and declined at the 2026-07-30 board review: a series resistor on
  HALL_TACH at the sensor end (signal is ≤3.3 Hz behind a 10 kΩ pull-up into a 2N7002
  gate with R45/C32 filtering at the LM2907; DRV5033 carries internal load-dump/reverse
  protection, and dead-tach is covered by the firmware FG-vs-Hall plausibility contract).
- Bracket (BR-100) handoff facts from the review: J1 is the board's tallest feature
  (~4.5 mm toward the rotor at its station, ~15 mm outboard of the sensor) — size axial
  clearance to it, not to the 1.1 mm sensor; the connector housing and cable extend past
  the 24 mm board edge, and all cable strain relief must come from the bracket (no board
  material exists beyond J1); at H1 use a bare pan head or washer ≤Ø4.5 (a standard Ø5
  washer leaves <0.35 mm to U1's pin-3 joint); solder the board before mounting it.
  The M2 hardware itself (screws ~6–10 mm, nylock nuts, ≤Ø4.5 washers, 1–3 mm spacers
  for axial gap shimming) is **not sourced from DigiKey** — their M2 catalog was
  verified bare on 2026-07-30 (one screw length, one plain nut, no washers/spacers);
  buy an Amazon M2 assortment or add to the next Accu order.

With the marker removed, run the GL100 through 0–180 RPM in both directions and require zero
Hall pulses from the motor magnets. With it installed, require exactly one pulse per
mechanical revolution. Any false pulse requires moving both sensor and marker to r82 in CAD,
not filtering or firmware compensation.

### Protected 12 V tach rail

Do not power the LM2907 from VM24 (its 28 V maximum is too close to the supply tolerance and
below the TVS clamp).

```text
VM24 -> 47 Ω / 0.25 W -> TPS7A1601ADGNR -> +12V_TACH (12.049 V nominal)
```

- LDO input: 10 µF / 63 V X7R + 100 nF / 100 V. EN tied to the filtered input.
- Feedback: 910 kΩ top, 100 kΩ bottom, both 0.1%. Feed-forward 10 nF / 50 V C0G output→FB.
- Output: 10 µF / 25 V X7R + 100 nF / 25 V.
- PG: 10 kΩ pull-up to 3.3 V, named `TACH_PGOOD_N`, routed to U6 `/CLR`.
- DELAY: **10 nF** to AGND (C31 on the released BOM), reduced from the original 100 nF so
  `TACH_PGOOD_N` releases well before the delayed U6 `/PRE`; PCB-03D qualifies the actual
  ordering on hardware.
- Connect both LM2907 pin 9 V+ and pin 8 collector only to +12V_TACH.

### LM2907M-14

- `HALL_TACH` carries the DRV5033's required **10 kΩ pull-up to 3.3 V** (R43 — the sensor
  output is open-drain; the daughterboard carries no pull-up of its own) and drives a 2N7002
  gate; the drain is pulled to +12V_TACH by 10 kΩ and feeds pin 1 TACH+ through 100 Ω
  (optional 1 nF C0G to AGND). This level shift keeps 3.3 V from driving an unpowered
  LM2907. *(Corrected 2026-07 board review: this section previously said "100 kΩ pulldown",
  contradicting the daughterboard section's pull-up requirement — as captured, the open-drain
  hall line was stuck low and the analog overspeed chain could never see an edge.)*
- Pin 11 TACH−: 6.0 V from a 10 kΩ / 10 kΩ divider on +12V_TACH, bypassed by 100 nF.
- C1: 100 nF, 1% C0G, **pin 2 (CP1) to AGND** (corrected 2026-07 review: the dossier said
  "pins 2 to 3", which dumps the ±180 µA pump current into the output filter node and voids
  the K-factor/linearity specs — both TI application figures ground the timing cap).
- Rscale: 562 kΩ 0.1% plus a 200 kΩ sealed ten-turn trimmer as a rheostat (wiper tied to one
  end), adjusted to approximately 656.1 kΩ total. Pin 3 carries only Rscale ∥ C2 to AGND.
- C2: provisional **2.2 µF** / 16 V X7R from pin 3 to AGND (baseline moved from 4.7 µF by
  the 2026-07 timing analysis — see the two-tier trip claim below), with DNP alternatives
  for 0.47, 1.0, 3.3, 4.7, and 6.8 µF (C36–C40 — schematic values now carry an explicit
  "DNP" suffix; the capture originally omitted it, which would have had all six populated in
  parallel for ~18.5 µF and a ~12 s trip lag). Final value selected by ripple and
  dynamic-trip testing.
- Pin 4 to pin 3; pin 10 to pin 5; **10 kΩ emitter load from pin 5 to AGND** (added 2026-07
  review: without it the follower has no pull-down path below the input clamp and
  falling-speed response is unspecified). Pin 5 is buffered VTACH. **Pin 12 to AGND.**
  Pins 6, 7, 13, 14 no connection.
- Nominal conversion after calibration: 13.175 mV/RPM. (Exact threshold model: with the
  open-collector output the rising trip computes to 199.6 RPM, not 200.0; the Rscale trim
  absorbs the difference.)
- 47 Ω dropper: rate **1 W** (an LDO current-limit fault dissipates up to ~7.5 W
  transiently in a 0.25 W part; 1 W survives indefinitely at the limited current).

Supply note: the LM2907 is TI-active (verified 2026-07) but it is the last monolithic F-to-V
family and stock is thin everywhere; buy spares with the V1 order. If supply ever dries up,
the fallback is a discrete charge-pump + comparator redesign of this stage, not a drop-in
(LM2917 variants change the input threshold architecture).
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

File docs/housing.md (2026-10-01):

# Housing specification

Functional specification for the final cosmetic housing. Michael owns its aesthetic design,
surface language, proportions, seams, colors, and detailed CAD. This document fixes only the
interfaces needed for acoustics, cooling, sensing, service, retention, and moving clearances.

## Owner status, 2026-09-30

Michael confirmed in the procurement reconciliation conversation (America/Vancouver) that
final tuning remains, then the aesthetic housing including the integrated Hall sensor holder
and sound dampening cover. He considers the sound dampening covering part of the housing.
The Hall harness itself is built and done; the integrated holder remains housing work.
This status records no new acoustic, thermal, or commissioning tests.

## Architecture

The housing is two mechanically separate assemblies with no contact across their running gap:

1. **Stationary upper enclosure:** spans from the MP-100 ceiling plate to the MC-100 stationary
   motor-carrier region. It encloses PCB-01, the standoffs, wiring, and the stationary motor mount.
   It provides the final stationary Hall-sensor mount.
2. **Rotating lower cover:** securely fixed to the RH-100/rotor assembly and rotating with the
   hub and GL100 outer rotor. It covers the rotor hub and the main rotating motor shell while
   preserving access and clearance for the catcher, nut, cotter, and spindle end.

The rotating hub continues to carry the tach magnet. The Hall sensor remains stationary so the
magnet crosses it once per revolution. Housing geometry may integrate both features, but may not
turn the sensor and magnet into one rigidly rotating assembly.

The aesthetic transition between the two sections may visually read as one form. The physical
interface remains an open, non-contact running gap sized from the realized runout and stack
tolerances.
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

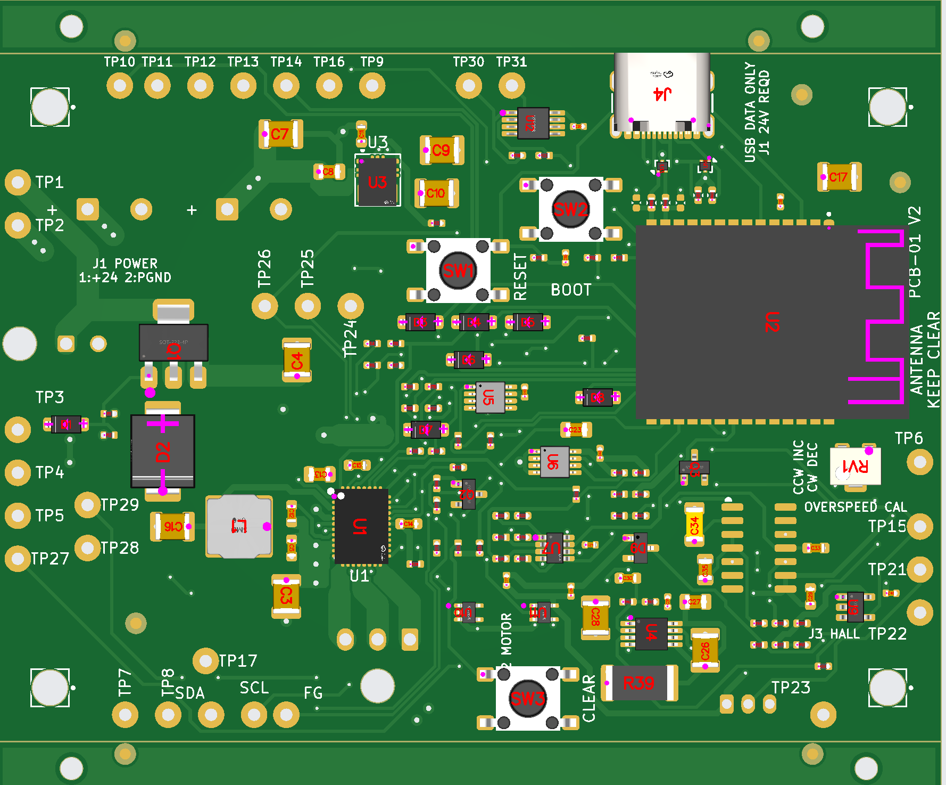
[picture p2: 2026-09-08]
pcb/pcb-01-v2/fab/placement-review/jlc-dfm.png

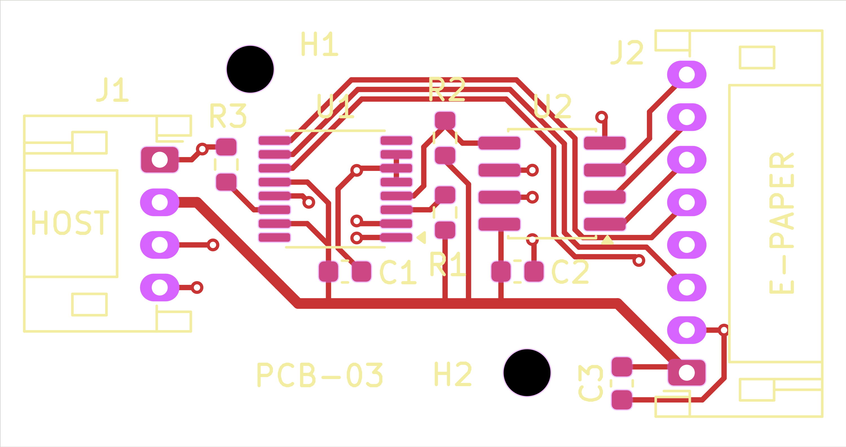
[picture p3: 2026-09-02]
pcb/pcb-03/placement/front.png

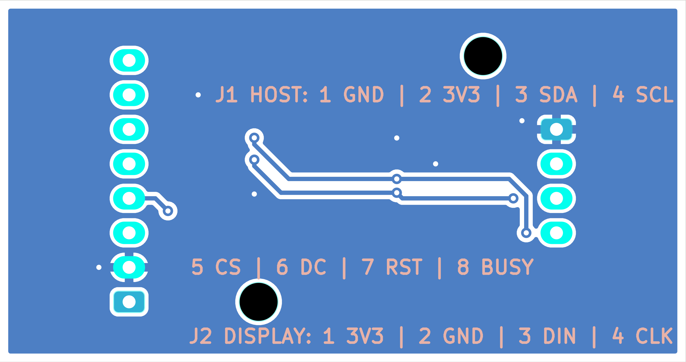
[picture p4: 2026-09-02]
pcb/pcb-03/placement/back.png

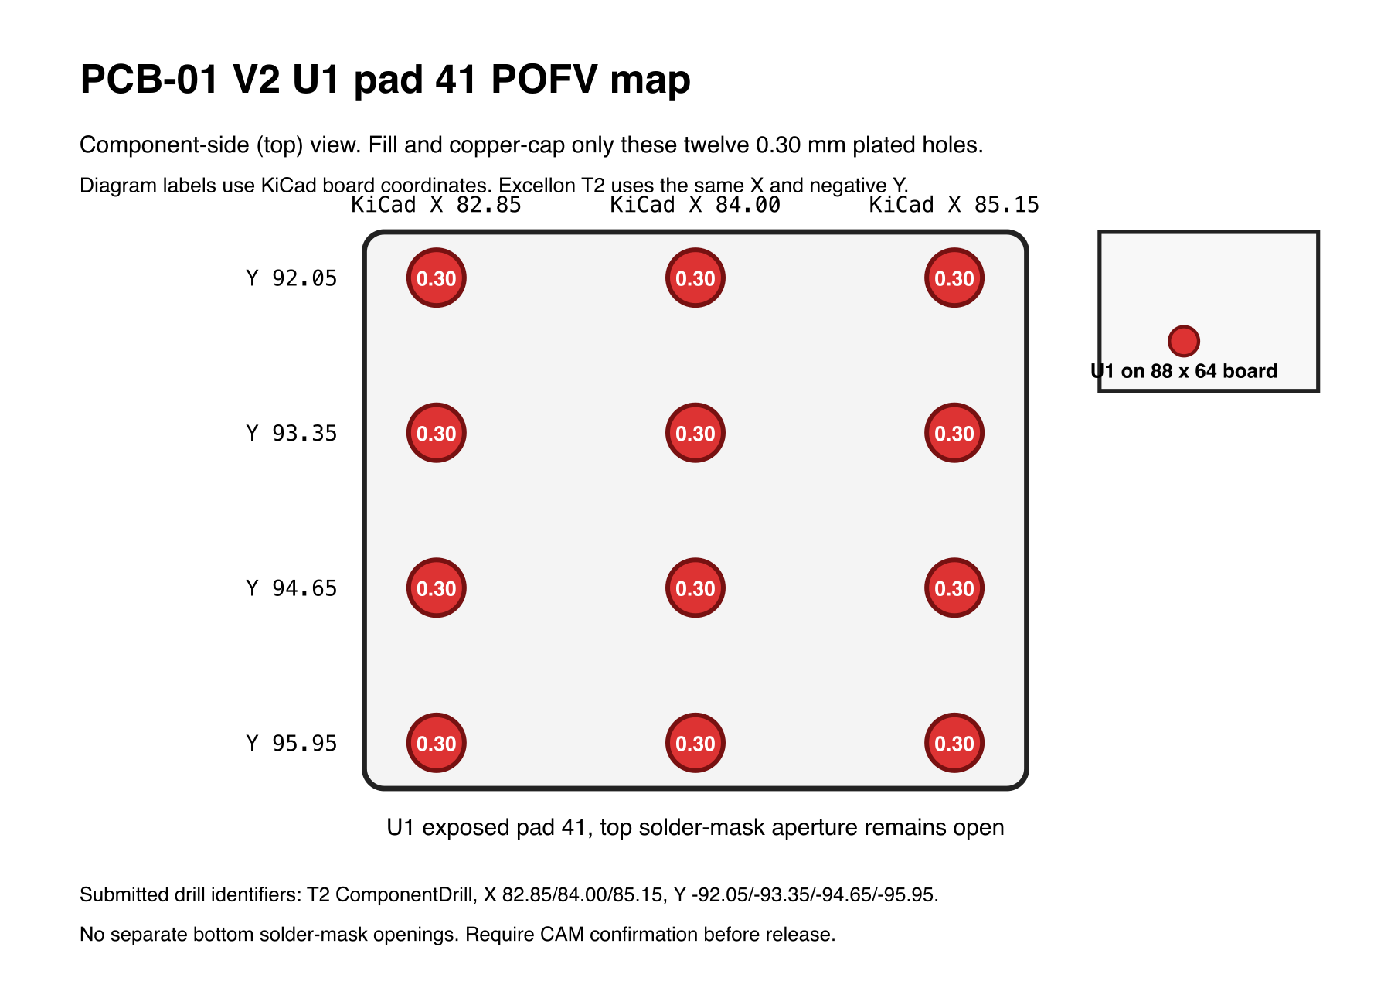
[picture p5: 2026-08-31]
pcb/pcb-01-v2/fab/pofv-location-map.png

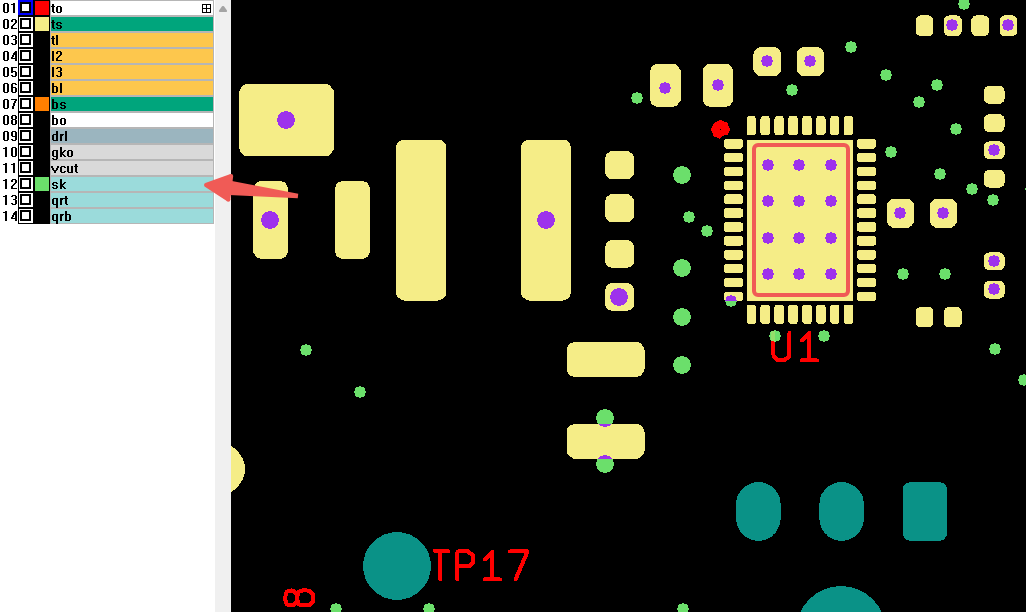
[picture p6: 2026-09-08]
pcb/pcb-01-v2/fab/production-review/pofv-confirmation.png

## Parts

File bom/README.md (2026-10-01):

# BOM

[`bom.csv`](bom.csv) is the canonical parts list with purchase tracking. Columns:

- **Design status** — the release state of the selection itself (selected, gated, V1-only).
  Gates reference [../docs/decisions.md](../docs/decisions.md) and
  [../docs/parts.md](../docs/parts.md).
- **Purchase status** — `Ordered (<vendor>)` / `Not ordered` / blocked notes. Update this
  column as orders go out and parts arrive (e.g. `Received`).
- **Order ref** — vendor order code (DigiKey part number, RobotShop product code).

- **Notes** — sourcing detail: LCSC part numbers (for the JLCPCB path), stock caveats,
  alternates. Stock counts are snapshots (dated) — re-verify before ordering.

Notes:

- Exact passive footprints (and any PCB-side mounting hardware) become orderable only after
  KiCad capture freezes their packages; they are intentionally not listed line-by-line yet.
  The **mechanical** fastener set was frozen by the 2026-07-27/28 CAD work and is now listed
  line-by-line with sourcing (2026-07-28 holistic pass). M3 hardware for EB-100/ENC-100/BR-100
  waits on those bracket designs.
- Custom mechanics (MP-100 through ENC-100) are fabricated per
  [../docs/parts.md](../docs/parts.md) and only after the motor and slab gates clear.
- Verify availability and price at order time.
- **Purchasing split** (decided pre-repo, carried forward): DigiKey Canada for off-board
  hardware, cable, connectors, and bring-up spares; Mouser for DigiKey stock gaps (the
  TPSM365R6V3RDNR has been out of stock at DigiKey before); JLCPCB turnkey sourcing for
  board-mounted parts when using their assembly — JLCPCB's overseas-consignment fees are
  uneconomic for a prototype, so consignment is effectively off the table.
- **JLCPCB path**: boards come from JLCPCB; PCBA vs hand-population is still open, but the
  owner is comfortable hand-installing SMD (confirmed 2026-07-28), so hand-population and
  the hand-solder-just-the-MCF hybrid are both live options. The 2026-07-28 DigiKey cart
  (Web ID 374750597, salesorder 100668200 — the number on the packing slip; received
  2026-08-01) deliberately holds only **LCSC-gap parts**: thin/absent-at-LCSC ICs
  and spares, Coilcraft (never on LCSC), Panasonic FR bulk caps, genuine JST PH headers,
  the GCT USB-C, cable-side housings/contacts, and the Hall daughterboard parts. As of 2026-07
  every IC except the exact `MCF8316DULVRGFR` variant is in the LCSC catalog, but all as
  Extended parts (per-part feeder fee), and LM2907M / TPS3435 stock is thin. Since
  consignment is uneconomic, the MCF choice for a PCBA run is: swap to the plain
  `MCF8316DVRGFR` after an equivalence check, or hand-solder just that part on an otherwise
  assembled board.
- Tools (crimpers etc.), wall-box enclosure hardware, and test equipment are deliberately out
  of scope for this BOM.
- **Common electronics bench hardware is also out of scope** (owner decision 2026-07-28):
  PCB standoffs, M3 mounting screws for boards, jumper wire, heat-shrink and similar
  commodity stock the owner already keeps on hand. Only project-specific or
  uncommon-spec hardware gets a BOM line.

## Owner reconciliation, 2026-09-30

Source: Michael's confirmations and latest project status in the procurement
reconciliation conversation on **2026-09-30, America/Vancouver**. Owner receipt
confirmation overrides older supplier shipping/delivery notices; it does not establish
new inspection, tuning, or commissioning results.

- Reviewed orders are received except **Mouser 40452969** and **DigiKey 101388939**.
  Received: DigiKey **101316601** (V2 loose parts), JLCPCB **W2026083117295494**
  (V2), JLCPCB **W2026090305011104** (PCB-03 boards/stencil), and AliExpress
  **8213753300045333** (Waveshare display). Reviewed recent AliExpress ESP boards
  and cables are also received; no unobserved counts, models, or cable specifications
  are inferred. Existing display and boards are retained.
- CrystalShim's DigiKey **101602605** (72 order lines) and JLCPCB
  **W2026091502305469** boards/stencils are received. Their allocations live in
  [CrystalShim's records](../../crystal-shim/bom/README.md), not this fan BOM.
- **Mouser 40452969 / sales 282002229** is not received: 17 pieces total,
  including six **M0599-4-N** spacers holding 11 in-stock electronics. Michael
  requested removal of all six spacers, not split shipment. The approved email
  was sent to canadasales@mouser.com at **2026-10-01 01:41 UTC**
  (**2026-09-30 18:41 Vancouver**). Vendor confirmation is pending; spacer removal
  is requested, not completed, and the remaining order awaits release.
- **DigiKey 101388939**, seven order lines, is not received. Michael dropped the
  optional e-ink addition and requested cancellation of the entire order. The
  approved email was sent to orders@digikey.com at **2026-10-01 01:41 UTC**
  (**2026-09-30 18:41 Vancouver**). Cancellation is requested, not vendor-confirmed.
  Do not buy the remaining J1 **S4B-PH-K-S** or **PHR-4**, or substitute an SC18IS
  chip. Retain the design and received display/boards; see [PCB-03](../docs/pcb-03.md).
- Historical DigiKey **100668200 / 100888768** remain received, with their original
  receipt dates below; **100616913 / 100723632** remain cancelled.
- The Stillair **PCB-01 J3 to PCB-02 J1 Hall harness is built and done**, by owner
  confirmation. Its retained wiring context is in [electrical.md](../docs/electrical.md).
  This is separate from CrystalShim's external sensor cable, and adds no test claim.
- Remaining fan work is **final tuning, then the aesthetic housing**, including the
  integrated Hall sensor holder and sound dampening cover. Interim installation is
  superseded as the primary next step. See [build.md](../docs/build.md) and
  [housing.md](../docs/housing.md); historical bench evidence remains unchanged.

BOM `Qty` is the design/allocation quantity. Purchase quantities stay in purchase-status
notes; receipt confirmation does not establish the current unconsumed loose-bin count.

## 2026-08-09 DigiKey consolidated order

DigiKey orders **100616913** and **100723632** were cancelled. Their cancellation invoices
(`130375795` and `130375791`) were checked line by line on 2026-08-09 and are the source of
truth for reconstructing the replacement basket. Order 100616913 contained 12 lines in
CAD/DDP; 100723632 contained 24 lines in USD/CPT. The four Micro-Fit connector families
appeared in both orders.

Use **one DigiKey Canada order paid in CAD** for the combined available basket. DigiKey's
Canadian CAD checkout is DDP, with duty and customs paid by DigiKey, and delivery is free
above CAD $100. A USD checkout is CPT and leaves tax, duty, and brokerage due on delivery;
that currency choice, not FedEx itself, caused the separate carrier bill on order 129980940.
Exclude Marketplace lines because they use supplier shipping and may be CPT even in a CAD
cart. The 30-line browser review cart **375208526**, named
`stillair-consolidated-reorder`, was checked line by line with no Marketplace, drop-ship,
or backordered offers. Before checkout, $46.37 of precautionary extras was removed: the
Panasonic bulk-cap, TLV1701 and SMD trimmer spare-only lines were dropped; power and motor
headers were reduced from 5 each to 2 each; S3B-PH-K-S from 2 to 1; NTCALUG from 2 to 1;
Keystone 24481 from 6 to 4; and C1206C104K3GACTU from 4 to 2. The useful connector
consumables, calibration parts and bench stock stayed.

The final 27-line basket was placed as DigiKey order **100888768** on 2026-08-09 and
received 2026-08-14 for
**CAD $179.45 before tax / $200.98 after BC GST+PST**, with free FedEx International
Priority. All lines were immediate-stock DigiKey warehouse items at checkout.

Mouser Canada is the runner-up: CAD orders can also be DDP and ship free above CAD $100,
but it does not offer the Belden 5300UE in project-sized cut lengths, and its exact E-Switch
was not immediately stocked in the comparison snapshot. Newark's small-quantity coverage
was worse (for example, the recovered 43650-0300 carried a 10-piece minimum from UK stock).
Splitting the basket loses the landed-price advantage without improving project readiness.

Pinned outside this order:

- `DMP6023LE-13` qty 2 loose spares: DigiKey stock zero; assembled boards already contain
  the required devices. Mouser had deep stock, so these are easy to revisit later.
- SparkFun `15362` qty 2: optional DNP scope headers, not normally stocked at DigiKey.

Four stock gaps stayed in the single DigiKey order through equivalent, same-footprint parts:

- KEMET `C0603C104K5RACTU` replaces Samsung `CL10B104KB8NNNC` (100 nF, 50 V, X7R, 0603).
- Vishay `PTN0603Y1002BST1` replaces Yageo `RT0603BRD0710KL` (10 kΩ, 0.1%, thin film,
  0603; power rating improves from 0.1 W to 0.15 W).
- KEMET `C0603C105K3RACTU` replaces Samsung `CL10B105KA8NNNC` (1 uF, 25 V, X7R, 0603).
- Taiyo Yuden `EMK107ABJ475KA-T` replaces Samsung `CL10A475KO8NNNC` (4.7 uF, 16 V,
  X5R, 0603).

The earlier fuse-holder mismatch was a reconstruction error. Invoice 130375795 confirms
that cancelled order 100616913 contained Littelfuse `FHAC0001ZXJ` / DigiKey `F3209-ND`, a
proper inline ATO holder, and it is in order 100888768. The formerly backordered Molex
`43650-0300` was also immediate-stock and is in that order.

Ordered so far: the GL100 KV10 motor (RobotShop), the MP-100 ceiling
plate (JLCCNC), and — 2026-07-28 — the complete mechanical fastener set including the
KD-100 catcher washers and Nord-Locks (Accu, $219.45 CAD), CW-100 brass rod (Amazon), and
the LCSC-gap electronics order 374750597 (DigiKey, ~$63 USD: insurance ICs and spares,
bulk caps, USB-C, cable-side JST housings/contacts, trimmers, dev cable), and the ST-100
standoffs (JLCCNC, qty 4, $101.79). The consolidated loose-parts basket was ordered from
DigiKey as **100888768** on 2026-08-09 ($200.98 CAD after tax). The V1 board run went out 2026-07-30 as JLCPCB
W2026073105230212 (boards + all LCSC-path parts via PCBA) with PCB-02 following the same
day as W2026073108244536. DigiKey **100723632** ($62.33, 24 lines: PCB-02's C1/J1,
the C34 1206 C0G, board-#2 completion headers, the J4 NTC element, EB-100 M3 standoffs,
tach-chain 0.1% spares, the C2 DNP calibration ladder, and bench spares) was placed
2026-07-30 and cancelled before fulfillment; its required and useful-stock lines were
reconciled into order 100888768 above.

PCB-01 V2 was ordered from JLCPCB on 2026-08-31 as **W2026083117295494**: five
88 x 64 mm boards with two top-side Standard PCBAs. Production approval remains gated on the
twelve U1 POFV holes, U3 pads 4/5 solder-mask-defined apertures, 97 ohm USB requirement, and
critical placement orientations in `pcb/pcb-01-v2/fab/ORDERING.md`. The complete hand-population
set for both assembled boards was ordered from DigiKey the same day as **101316601**: four
`EEU-FR1H471` and two each of `43045-0200`, `43650-0300`, `B3B-PH-K-S(LF)(SN)`, and
`LM2907M/NOPB`. This order deliberately does not depend on uncertain loose stock from V1.
JLCPCB's order-message team and Paul separately confirmed on 2026-08-31 that the PCB Remark and
mandatory CAM attachments reached engineering. The DFM initially visible on the order page is an
automated preliminary version; engineering is regenerating the final DFM, and no approval is due
until its Confirm button activates. Their acknowledgment is not acceptance of the three technical
requirements, so explicit final confirmation remains mandatory.

On 2026-09-14 Michael reported that PCB-01 V2 is in production. This supersedes the earlier
awaiting-approval status above; no new factory files were reviewed in this session.

Arrivals 2026-08-01: the GL100 motor (RobotShop), the complete Accu fastener order, the
ohcanadasupply.ca Titen HD anchors, and DigiKey 374750597 (salesorder 100668200 on the
packing slip). Arrivals 2026-08-14: DigiKey 100888768, PCB-01, PCB-02, all JLCCNC parts
(MP-100, four ST-100s, SP-100, MC-100, RH-100), and the completed owner-manufactured
BP-100 blade set. The owner accepted the delivered parts and order contents as received;
blade-root qualification MEC-01/02/02B passed by owner report. MEC-05 assembled rotor
balance/runout remains open.

One of the two assembled PCB-01s from JLCPCB order **W2026073105230212** has a
non-enumerating U2 native-USB interface despite valid power rails, forced ROM boot, known-good
cables, intact series resistors, and no USB-line short. A PCBA quality complaint requesting a
replacement was submitted 2026-08-28 at 19:39:21 against SMT job
**SMT026073063521-12177845A**, with four board photos and `IMG_3587.mov`. The reloaded JLCPCB
result page showed **Submitted / Processing** and promised a response within 24 hours; it exposed
no separate case number. The other assembled board from the same design has working native USB,
which isolates the failure to the affected board rather than the schematic or PCB design. Support
asked for short/solder checks, removal of U2, and the schematic; Michael replied with the completed
electrical checks and schematic package and declined destructive removal because U2 has hidden LGA
pads. The likely fault remains a hidden U2 USB-pad joint or U2 itself.

In the follow-up email supplied by Michael on 2026-09-14, Paul apologized for the delayed
response and confirmed that `C6553337` had not received X-ray inspection during production.
JLCPCB therefore could not confirm the condition of its hidden solder joints. Paul is checking
repair feasibility and offered free repair, round-trip shipping, and applicable duties if repair
is feasible; coverage is limited to soldering abnormalities or component replacement, excluding
functional/design problems. No repair or pickup has been accepted. With V2 already in production,
Michael considers V1 superseded and prefers a credit or discount against V2 order
**W2026083117295494**, without returning V1. He also reports substantial recent spending and
additional JLCPCB orders for two other projects. Michael approved a reply requesting credit for
the affected assembled board's cost, including components and assembly, as a discount or partial
refund against V2. The [approved draft](../docs/jlcpcb-v1-credit-request.md) was copied to his
clipboard and verified with `pbpaste` on 2026-09-14. Paul's subsequent response confirms receipt
of the credit request; the agent did not send it. No fixed dollar amount or percentage was
proposed in that request, and no credit is agreed.

The thread supplied on 2026-09-15 records JLCPCB declining credit or partial refund against an
already-placed order. Paul instead offered to try to obtain a USD 30 future-order coupon or
free expedite service for V2 (`SMT026083161536`), quoting a normal expedite fee of USD 45–80.
Michael asked to expedite both current orders, **W2026083117295494** and the newly placed
**W2026091502305469**; the latter's project and contents are unspecified. Paul limited the
offer to one order and asked whether to apply it to V2, which he confirmed was in production.
Michael is dissatisfied and now wants to reject the offer and say this support interaction will
factor into future purchasing decisions. The [rejection draft and reply history](../docs/jlcpcb-v1-credit-request.md)
are retained; the rejection has not been sent by the agent or reported sent by Michael.
No coupon or expedite service is confirmed, and the complaint remains unresolved.

The motor-gated CNC batch went out 2026-08-02 as JLCCNC **W2026080301372216** ($204.44
shipped): SP-100 $82.76 (SUS304 — JLCCNC stocks no 17-4PH; margin math in parts.md),
MC-100 $48.83 and RH-100 $42.08 (both 6061-T6, bead blast + natural matte anodize;
RH-100 on the ±0.05 tolerance tier so the measured-bore pilot fit is contractual, the
one paid tier in the batch that's functionally load-bearing).

DigiKey cart mechanics (learned building 100723632 via browser automation): the cart
page's Bulk Add box takes `qty, part-number` lines but **silently drops MPNs that have
multiple packaging variants** (cut tape / reel / Digi-Reel) — use packaging-specific
DigiKey numbers (the `-1-ND` / `...CT-ND` forms, findable on each product page) for
anything taped; single-listing MPNs (connectors, hardware) resolve fine as bare MPNs.
Verify the cart line MPNs after a bulk add rather than trusting the submit.

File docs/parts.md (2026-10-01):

# Part specifications (CAD handoff)

> **Temporary**: the original dimensioned drawing diagrams (assembly section, plate/carrier/hub
> top views, blade plan, capture detail) are still viewable at
> https://stillair-fan-design.syas.chatgpt.site/drawings (requires ChatGPT auth). Remove this
> link once the OnShape model reproduces them.

Dimensioned starting design for every fabricated part, one step before production drawings.
Z = 0 at the finished ceiling, positive Z down (see [mechanical.md](mechanical.md) for the
stack and coordinate system). Import the current CubeMars GL100 STEP and physically verify
every motor-dependent dimension before ordering machined parts. Final models are built in
OnShape; exports and 2D fabrication files land in [`cad/`](../cad/).

GL100 sources (use the current Ø106.8 × 34.2 mm revision, **not** the older Ø95 × 37.1 mm
drawing):

- Product page: https://www.cubemars.com/product/gl100-kv10-gimbal-motor.html
- Official 2D drawing: https://www.cubemars.com/data/cms/202602/gl100-gimbal-motor-2d-drawing.pdf
- Official STEP package: https://www.cubemars.com/data/cms/202602/gl100-gimbal-motor-3d-drawing.zip

## GL100 release checks

> **Status 2026-08-01 (motor in hand)**: current revision **confirmed** (Ø106.8 × 34.2;
> axial length measured 34.2–34.3 across clockings). Face ownership **confirmed**: Ø50/M4
> rotates (output face), Ø60/M4 and Ø100/M2.5 are stationary, and the bore surface rotates
> with the Ø50 face — so the RH-100 pilot mates a rotating surface, as the catcher's
> clean-drop assumption requires. Owner decision (2026-08-01): with the revision confirmed,
> STEP-derived geometry (hole positions, PCDs, wire-exit location) is trusted as-is and
> thread depths are verified at assembly rather than pre-measured — bench measurement is
> reserved for dimensions feeding non-adjustable machined features (KD-100 thickness →
> SP-100 cross-hole; pilot bore ID → RH-100 pilot OD, owner's call).

- Official envelope: Ø106.8 × 34.2 mm, Ø30 bore, 698 g, 20 pole pairs.
- Front interface: 4 × M4 on Ø50 PCD, 3.5 mm maximum thread depth.
- Rear inner interface: 4 × M4 on Ø60 PCD, 6.0 mm maximum depth.
- Rear outer interface: 6 × M2.5 on Ø100 PCD, 4.0 mm maximum depth.
- Confirm that Ø50/M4 is the rotating output face and Ø60/M4 is stationary.
- Measure both bore faces, determine which bore surfaces rotate, and depth-pin both M4 patterns.
- Import the STEP to locate the wire exit, steps, chamfers, contact annuli, and face ownership.
- Obtain or disposition the continuous axial/radial load, overturning moment, external rotor
  inertia, and bearing-life basis for vertical-axis operation.
- Do not use the Ø100/M2.5 pattern structurally until its ownership is physically confirmed.

### Bearing-data request (Gate 01, researched 2026-07)

**Status: sent to info@cubemars.com on 2026-07-27** (the question list below, plus written
confirmation of the M4 face ownership/thread depths and allowable M4 installation torque).
Awaiting reply.

No public bearing or load data exists for the GL series (checked every storefront and
CubeMars' guides; their technical-support page hosts full manuals for the AK actuator line
but nothing for GL, and they do publish load ratings for actuators — so a direct ask is
precedented, via info@cubemars.com). What the research could bound:

- The ~20–30 N axial hang (2–3 kg rotor) is almost certainly trivial: any plausible bearing
  in a Ø106.8 × 34.2 housing with a Ø30 bore carries multi-kN catalog ratings.
- The genuine unknowns are **overturning-moment capacity** (blade imbalance loads react as an
  edge-load couple across whatever bearing spacing exists inside a 34.2 mm pancake) and
  whether it's a single bearing or a spaced pair.
- 35–170 RPM continuous duty is favorable for bearing fatigue life (few load cycles per unit
  time).
- Additional published data found: rotor inertia 2310 g·cm², IP45, −20 to 50 °C operating
  range, Kv 9.3 RPM/V.

Questions to send CubeMars: (1) bearing type/part number/quantity/axial spacing in the
current GL100 revision; (2) continuous axial (thrust) rating, axis vertical; (3) continuous
radial rating; (4) allowable overturning moment and its evaluation radius; (5) documented
L10 life at 35–170 RPM under ~30 N axial; (6) precedent continuously-rotating hanging
deployments (radar heads) and whether mass rode on the motor bearings; (7) whether they
recommend an external thrust bearing for hanging loads; (8) whether a GL-series mechanical
manual exists like the AK-series ones.

Fallback if data never comes (this gives Gate 01's "independently rated bearing path"
concrete shape): an external thrust/slew bearing carries the rotor weight and moment, and
the GL100 transmits torque only through a non-structural coupling.

## MP-100 ceiling plate

> **Status: RECEIVED + OWNER-ACCEPTED 2026-08-14** (JLCCNC, SUS304, brushed,
> qty 1, ~$130). Rev A files are
> [`cad/MP-100_revA.step`](../cad/MP-100_revA.step) and
> [`cad/MP-100_revA.pdf`](../cad/MP-100_revA.pdf) — the first custom part committed to metal.
> Any change from here is a rev B, not an edit.

- Ø210 × 6.0 mm 304 stainless disk, flat within 0.30 mm, brushed and passivated.
  **Passivation is not on JLCCNC's finish list for 304** — the ordered part is brushed only.
  304 self-passivates in air; do it with a citric-acid kit if the spec is to be met literally.
- Two 11 × 20 mm radial anchor slots centered at X±65, Y0 (130 mm anchor centers).
- Three Ø6.6 standoff holes on Ø150 PCD at 90°, 210°, 330°, countersunk from the ceiling face
  for M6 flat-head screws.
- Center spindle opening Ø16.2; top-face flange recess Ø34.2 × 3.1 deep, cut as a **double-D
  pocket**: two parallel flats **30.4 mm across** (+0.3/−0.0), normal to Y, giving 0.2–0.35 mm
  clearance per side on SP-100's 30.0 mm flats (band widened 2026-07-27 from +0.1/+0.2 so the
  feature lands inside a shop's standard ±0.1 and needs no tight-tolerance surcharge; even at
  the loose end the rotational slack is ~1.3°, irrelevant for anti-rotation). This keys the spindle against rotation so the
  M12 castellated nut can be torqued from below with no counter-hold (2026-07-27).
- Separate tether-anchor clearance at X0, Y−82: 14 × 22 mm.
- Cable entry: **none in the plate** (the 12 × 20 mm slot was deleted 2026-07-27 — see
  "Cable entry" below). Instead, two M3 × 0.5 tapped holes on 20 mm pitch in the underside
  at r88, straddling the **15°** line, for a P-clip strain relief.
- EB-100 mounting: two M3 × 0.5 tapped holes at X35, Y±15 from the underside; keep clear of
  ceiling anchors and spindle recess.
- ENC-100 mounting: six M3 tapped holes at r96, **clocked 45°/105°/165°/225°/285°/345°**
  (locked 2026-07-27; see "ENC-100 tab clocking" below for the margin table and the rejected
  alternatives).
- **All ten underside taps are M3 × 0.5, blind: 3.5 mm thread depth, 5.0 mm drill depth**,
  leaving a 1.0 mm floor in the 6.0 mm plate (specified 2026-07-27; thread cut from 4.0 mm
  and the cable pair from M4 on 2026-07-27 to satisfy JLCCNC's blind-tap DFM rule, which
  wants ≥ half the nominal diameter left unthreaded at the bottom — 3.5 + 1.5 in a 5.0 drill
  meets it exactly for M3, where M4 would not). None break through — a through-tapped hole
  lets an over-length screw protrude into the ceiling seating interface. One tap size across
  all ten holes is also one tool and one setup.
  Cable-clamp tap centres from the released drawing: **(87.03, 13.65)** and
  **(81.88, 32.89)**. Use the relational 15° line for installation orientation rather than
  reproducing these coordinates on the ceiling.
- Hard metal spacers bypass any soft ceiling finish.

Anchor gate: the slots accept nominal M10 or 3/8-inch hardware. Selected candidate (2026-07,
~7× tension margin in cracked concrete): Hilti KB-TZ2 3/8 in stainless at hef 2 in — full
numbers, tether anchor, and the pre-drill verification checklist in
[install.md](install.md). Not released until the slab is verified per that checklist.

## ST-100 carrier standoffs

> **Status: RECEIVED + OWNER-ACCEPTED 2026-08-14** (JLCCNC, 6061-T6 clear
> anodized, qty 4, $101.79). Rev A
> files are [`cad/ST-100_revA.step`](../cad/ST-100_revA.step) and
> [`cad/ST-100_revA.pdf`](../cad/ST-100_revA.pdf). Any change from here is a rev B.

Three Ø16.0 × 62.0 ±0.10 mm 6061-T6 posts, end squareness 0.05 mm, M6 × 1 tapped at least
12 mm deep at both ends. (Shortened from 138.0 in the 2026-07-27/28 rotor raise — see
[mechanical.md](mechanical.md) > Envelope; the vertical-PCB assumption that sized the 138
moved with it, see [electrical.md](electrical.md).)

> **No off-the-shelf substitute exists (searched 2026-07-28)**: every configurable catalog
> standoff line caps below 62 mm — MISUMI tapped spacers hard-cap at 50 mm (and offer 2017,
> not 6061), McMaster's only aluminum M6 female-female standoff is 52 mm hex, Accu's
> threaded-spacer catalog has no aluminum at all. Stays CNC; a simple lathe part anyway.

- Top: M6 × 16 A4-80 flat-head screws through MP-100, at least 9 mm engagement after countersink.
- Bottom: **M6 × 20** A4-80 socket screws through MC-100 with wedge-locking washers
  (lengthened from M6 × 18 in the 2026-07 review: socket length is measured under the head,
  and a wedge-lock *pair* is ~3.5 mm, leaving only ~6.5 mm engagement at 18 mm — below the
  1.5×D guideline for aluminum threads; 20 mm restores ~8.5 mm with the pair, which is
  **accepted at 1.4×D** given the tiny joint loads and the joint-analysis torque, with the
  actual washer-stack thickness stated on the drawing; washer stacks ≤3 mm reach the full
  9 mm guideline). **Installed target selected 2026-08-20: 5 N·m**, tightened evenly in a
  triangular sequence with no threadlocker. This intentionally stays below Nord-Lock's generic
  8.4 N·m A4-80/M6 guidance because that table assumes Cu/C lubrication and does not account
  for this joint's tapped 6061-T6 standoffs.

Fabrication callouts (pre-order check 2026-07-28):

- **Tap drill Ø5.0 × 15.5 mm deep, thread M6 × 1 − 6H × 12.0 mm min, both ends.** The
  15.5 drill satisfies JLCCNC's blind-tap DFM rule (≥ 0.5 × nominal Ø unthreaded below the
  thread: 12 + 3 = 15 min). Two 15.5 drills in a 62 part leave a 31 mm solid web — no
  break-through risk.
- Screw-bottoming check passes with margin: worst protrusion into the tap is ~10 mm (top
  M6 × 16 flat-head through the countersunk 6 mm plate; bottom M6 × 20 through 8 mm MC-100
  plus the wedge-lock pair) against 12 mm of thread.
- Thread-entry chamfer 0.5 × 45°; break all edges.
- The 62.0 ±0.10 length and 0.05 end squareness are tighter than ISO 2768-mK, so they are
  drawing/remark callouts — and per the MP-100 precedent JLCCNC treats those as advisory,
  not contractual. Both are natural lathe outcomes (three parts faced in one setup match
  closely); **verify on arrival with calipers and a square before mounting**, as with the
  MP-100 flatness check.
- Tap concentricity to the OD is deliberately uncontrolled — the joint locates through the
  Ø6.6 clearance holes in both plates, which absorb ordinary drill wander.
- Qty: 3 required; order 4–5 (turned-part marginal cost is small and a dropped or
  cross-threaded spare otherwise costs a full shipping cycle).

## MC-100 stationary motor carrier

> **Status: Rev A RECEIVED + OWNER-ACCEPTED 2026-08-14** (JLCCNC
> W2026080301372216, $48.83;
> bead blast + natural matte anodize) —
> [`cad/MC-100_revA.step`](../cad/MC-100_revA.step) +
> [`cad/MC-100_revA.pdf`](../cad/MC-100_revA.pdf). On arrival: straightedge the motor
> face (0.08 flatness is advisory at 2768-medium) and chase the two M3 taps with a screw
> (anodize film, ST-100 precedent).

- Ø180 × 8.0 mm 6061-T6, clear anodized (OD trimmed 188 → 180, 2026-07-28 owner tweak in
  OnShape; rim past the Ø16 standoff posts is 7 mm, tether-hole edge margin ~9.7 mm, ENC-100
  internal clearance improves).
- Motor interface flat within 0.08 mm; runout to axis within 0.08 mm TIR.
- Three Ø6.6 holes on Ø150 PCD at 90°, 210°, 330°.
- Four Ø4.5 holes on Ø60 PCD, clocked from the current GL100 STEP. Counterbore Ø7.5 × 1.5
  from above.
- Center clearance Ø20.5.
- Two Ø8.5 tether holes at X±7, Y−76.
- Two Hall-bracket M3 × 0.5 tapped through holes (no counterbore/countersink — heads bear
  on BR-100's slotted feet) on 12 mm pitch at r71 (as-modeled r71.25 — the BR-100 slots
  absorb it), on the **150° line — the bisector
  between two adjacent ST-100 standoff holes** (owner move 2026-08-01, from 30°: the
  sensor angle is free since the magnet sweeps the full r76 circle; clearances unchanged —
  60° to each adjacent standoff bolt head, 15° min to the nearest ENC-100 tab, ~74° to the
  phase window. Angular labels are frame-ambiguous across model sketches — the controlling
  definition is the standoff-bisector, not the number).
- Nominal phase-lead window 20 × 12 R3; final location from the STEP and physical motor.
- Use four M4 × 12 A4-80 screws. The counterbore produces approximately 5.5 mm motor-thread
  engagement against the official 6.0 mm maximum. Verify first. **Installed 2026-08-20:** all
  four fit without bottoming and clamped the motor to MC-100 using blue removable threadlocker
  and an approximately 1.5 N·m hand-torque target.

## SP-100 capture spindle

> **Status: Rev A RECEIVED + OWNER-ACCEPTED 2026-08-14** (JLCCNC
> W2026080301372216, $82.76) —
> [`cad/SP-100_revA.step`](../cad/SP-100_revA.step) +
> [`cad/SP-100_revA.pdf`](../cad/SP-100_revA.pdf), cross-hole at measured Z136.58.
> **Ordered in SUS304, not 17-4PH** (JLCCNC stocks no 17-4PH; accepted 2026-08-02:
> ~13× yield margin at the 1.25 kN proof, the part is stationary so there's no fatigue
> driver, and the proof test remains the release evidence — the PDF's 17-4PH note is
> superseded by the order config; correct it at any rev B). Install note: the A4 nut on
> a 304 thread is stainless-on-stainless — **anti-seize at the one-time install**.
> On arrival: check flats/concentricity with calipers (2768-medium ordered; tight
> callouts advisory per the MP-100/ST-100 precedent).

- One-piece 17-4PH H1150 stainless, passivated.
- Ø16.0 shank; Ø34 × 3.0 upper flange; straightness 0.10 mm; concentricity 0.05 mm TIR.
- Ø16 shank runs from Z3 to the disk shoulder at Z120.7.
- M12 × 1.75 thread from Z120.7 to **Z142.0** (21.3 mm long), with the runout inside the
  Z120.7 shoulder. (A same-day 2026-07-28 excursion to Z144.0 for a 6 mm Amazon washer was
  reverted when the DIN 440 4 mm washer was selected instead.)
- **Ø3.2 cotter cross-hole, centreline at Z136.6** (**set 2026-08-01 from the measured
  washer: t = 3.38 → Z = 3.38 + 133.2 = 136.58, drawn as 136.6**; supersedes the 4.0-nominal
  Z137.2), perpendicular to the flange flats.
- (All Z values shifted −76 total in the 2026-07-27/28 rotor raise with the shortened
  ST-100; the bottom-end geometry is unchanged relative to the hub. In OnShape these dims
  are driven by `#hubBottom` expressions.)

### SP-100 bottom-end stack (derived 2026-07-27)

Both dimensions above were previously "approximately Z218" and an unlocated Ø3.2 hole, so
the part could not be drawn. They derive from the retaining nut, fixed here as a **DIN 935
M12 A4 castellated nut** (s 19.0, total height m 15.0, unslotted height m′ 10.0, six 3.2 mm
slots) with an **ISO 1234 3.2 × 32 A4 split pin** (trim legs to suit). The nut installs
bearing-face-up against KD-100, castellated crown downward.

| Z, mm | Feature |
|---:|---|
| 120.7 | Ø16→M12 shoulder; thread starts. KD-100 clamps up against this face |
| 120.7–124.7 | KD-100, 4.0 mm nominal (DIN 440 band 3.4–4.6), its Ø13.5 bore over the thread |
| 124.7 | Nut bearing face |
| 124.7–134.7 | Nut unslotted body (m′ = 10.0) |
| 134.7–139.7 | Castellated crown, 5.0 mm of slot depth |
| **137.2** | **Cotter cross-hole centreline** (nominal at t = 4.0; **machine at Z136.6 per measured t = 3.38**) — mid-band |
| 142.0 | Thread ends, 2.3 mm (>1 pitch) below the crown |

- The hole is centred in the 5.0 mm slot band so the cotter has material both sides. The
  DIN 440 washer's ±0.6 thickness band would eat the 0.9 mm margins at its extremes, so
  the cross-hole Z is **set from the measured washer thickness** (Z = t + 133.2) before
  SP-100 is machined — with a measured t, the remaining stack tolerance (shoulder position,
  nut m′) is back to ~±0.2 and the hole stays comfortably inside the band.
  **Measured 2026-08-01: t = 3.38 mm → Z136.6** (slot band 134.08–139.08 at that t; the
  hole is dead-center with 2.5 mm both sides). Single washer measured; the three are one
  stamping batch, so siblings track within a few hundredths — any of them installs. Thread
  end stays Z142.0 (now 2.9 mm past the crown; more margin, not less).
- Six castellations on a 1.75 mm pitch give **0.292 mm of axial adjustment per index step**,
  so worst-case seating error after aligning a slot is 0.146 mm. Rotate the *nut* to find
  alignment; the spindle is keyed and does not turn.
- Cross-hole clocking is set perpendicular to the flange flats so the drawing is
  deterministic; nothing depends on it (a castellated nut aligns to any hole angle).
- Ø3.2 through a Ø12 thread leaves 4.4 mm of material each side. The nut hangs at r ≤ 11 in
  free space — RH-100 ends at Z118.2 above it, and the blade roots start at r52.
- **Anti-rotation (dimensioned 2026-07-27; supersedes the 2026-07 review's wrench-flat
  note)**: two parallel flats on the flange OD, **30.0 mm across flats** (−0.1/−0.2),
  symmetric about the axis, cut through the full 3.0 mm flange thickness, flat faces normal
  to Y. Flat depth 2.0 mm per side, chord width 16.0 mm; break the flat/OD corners.
  MP-100's recess is a **matching double-D pocket** (see MP-100 above), so the plate keys
  the spindle against rotation permanently and **no counter-hold is required** when torquing
  the M12 nut. 30.0 mm is a standard wrench size, so the flats still take a wrench on the
  bench.
- Why keyed rather than wrenched: the flange is bench-assembled into a recess that opens
  toward the ceiling, but the castellated nut goes on at install step 4, *after* the plate is
  anchored — by then the flange is inaccessible above the plate, and the only exposed shank
  is the 2.5 mm capture gap. The hard ceiling spacers mean the slab does not directly clamp
  the flange. Wrench flats alone would have solved the bench
  case and left the real one unsolved.
- Load check (both trivial, recorded so the flats are not re-litigated): flats cost 6% of the
  flange bearing annulus (701.7 → 658.5 mm², **1.9 MPa** at the 1.25 kN static proof); the
  flat/pocket interface sees **13.9 MPa** reacting 20 N·m of nut torque across 2 × 48 mm².
- Anti-rattle retention: seat the flange metal-on-metal on the pocket shoulder, then bridge
  the ceiling-side perimeter seam to MP-100 with three tiny dots of non-corrosive neutral-cure
  RTV. Do not put elastomer under the flange or in the proof-load bearing interface. Cure
  fully in air, then tap/shake to verify no metallic click. The RTV is serviceable damping,
  not structural retention; before it cures, use a simple recess-up holding fixture with the
  spindle hanging through a hole.
- The upper flange sits captive in MP-100 (the Ø34.2→Ø16.2 bore step is a real internal
  shoulder — retention is self-contained in the plate, not ceiling-dependent). The disk
  seats on the machined Z120.7 shoulder, so the capture gap is not set by loose washers.
- The spindle passes through MC-100, the GL100 bore, and RH-100 without normal contact.

## RH-100 captured rotor hub

> **Status: Rev A RECEIVED + OWNER-ACCEPTED 2026-08-14** (JLCCNC
> W2026080301372216, $42.08;
> bead blast + natural matte anodize; **±0.05 tolerance tier bought deliberately** —
> 2768-medium would legally allow a Ø30.05 pilot, an interference fit on the measured
> Ø29.99 bore) — [`cad/RH-100_revA.step`](../cad/RH-100_revA.step) +
> [`cad/RH-100_revA.pdf`](../cad/RH-100_revA.pdf). On arrival: the pilot must slip into
> the motor bore by hand, no force; check M4 flat heads sit 0.1–0.2 subflush with the
> real screws.

- Ø200 × 8.0 mm 6061-T6, flat within 0.08 mm and OD concentric to pilot within 0.05 mm TIR.
- **Restyled 2026-07-28 (owner, in OnShape)**: no longer a full disk — a three-arm spoke
  plate, arms on the 0/120/240 station lines out to r100 with sculpted concave waists
  between. All interfaces unchanged (center bore, Ø50 PCD, pilot, stations); final outline
  lives in the OnShape model and exports at drawing release (the restyle prompted moving
  the tach stations onto the arms — see "Tach features"); flatness/TIR specs apply to what
  remains.
- Center hole Ø20.5.
- Four Ø4.5 holes on Ø50 PCD with 90° countersinks from the underside for ISO 10642 M4 × 10
  A4-80 flat-head screws. Install heads 0.1–0.2 mm subflush. Nominal motor engagement is
  2.0 mm, below the official 3.5 mm maximum.
- Top annular pilot protrudes 1.5 mm into the motor bore. Keep pilot ID Ø20.5. Final OD is
  the measured mating diameter minus 0.10–0.20 mm diametrical clearance. **Released
  2026-08-01: bore measured Ø29.99–30.00 → pilot OD Ø29.85 (band 29.80–29.90).**
- Three blade-root stations at 0°, 120°, 240°. Each station: 4× Ø5.5 through-holes + 2×
  blind Ø5 H7 × 4 dowel holes. **v3 (2026-07-28): the BP-100 blade bolts here directly** —
  its printed Ø5 pins engage the dowel holes (steel dowels deleted), M5 bolts from above
  into nut pockets in the blade root. **Station hole positions were customized by the
  owner in-model 2026-08-02** (original nominals were r62/r88 ±15 bolts, r66/r86 dowels);
  the released STEP is the interface truth, and the matching blade-root pattern is
  owner-managed in the BP-100 print (not tracked here).

Tach features:

- **Three identical stations, one per arm (moved 2026-07-28)**: **Ø6.45 × 3.35** blind
  pockets in the top face at **r76 on the three arm/station centerlines** (0/120/240).
  (Resized 2026-07-28 from Ø6.10 × 3.15 for the purchased imperial magnet — Ø6.35 × 3.18,
  1/4 × 1/8 in; metric 6 × 3 N52 proved uneconomic to source in Canada.) The
  spoke restyle removed material at the old 30°/210° waist positions, and an
  opposite-the-magnet counterweight can never sit on an arm — so instead one station holds
  the Ø6.35 × 3.18 axially magnetized N52 disk and the other two hold brass slugs trimmed to
  the same installed mass: three equal masses at 120° spacing balance by symmetry, and the
  Hall still sees exactly one magnet per revolution (brass is non-magnetic). r76 centers
  between the r66/r86 dowel holes on the arm centerline (10 mm clear of each).
- **MR-100 retaining caps deleted 2026-08-01 (owner decision)**: magnet and slugs are
  **epoxied** into their pockets — no caps, no M2 taps on RH-100 (6 tapped holes removed;
  no tapping cost). Basis: retention load is trivial (~0.02 N centrifugal on a ~0.75 g
  magnet at 170 RPM; the pocket wall takes the radial component, epoxy only carries the
  axial ~nothing), and the owner accepts epoxy as the retention method. The M2 × 5 screws
  (Accu, received) are surplus. With the 0.8 mm cap gone the magnet face sits ~0.17 mm
  below the hub top (3.35 pocket − 3.18 magnet); BR-100 targets the same 2.5 mm nominal
  air gap at fit-up — effective magnet gap ~2.7 mm, well inside the 1.5–4.0 window.
- **CW slugs are not same-size copies**: a same-size brass copy is ~13% heavier than the
  magnet (brass 8.5 vs NdFeB ~7.5 g/cm³); trim to ~Ø6.35 × 2.8 mm to match (cut from
  1/4 in rod); the ~0.55 mm recess above each slug fills with epoxy.
- Match complete station masses (insert + its epoxy) within 0.01 g across all three
  stations. **Epoxy is the retention** (2026-08-01; supersedes "adhesive controls rattle
  only").

## KD-100 catcher disk

- **Purchased part (final selection 2026-07-28)**: **Accu HDW-M12-A4** — DIN 440 washer,
  A4, **Ø44 OD × Ø13.5 ID × 4.0 nominal** (DIN 440 thickness band 3.4–4.6), stamped, ~$7
  each, qty 3 in the Accu fastener order. Supersedes the same-day Amazon Ø50 × Ø12 × 6
  machined-washer pick (cancelled: the Ø12 bore was a zero-clearance fit on M12 and it
  added a vendor; the Ø13.5 DIN 440 bore clears properly). The 4.0 thickness restores the
  original bottom-end stack derivation (cotter Z137.2, thread end Z142.0).
- **OD 44 vs the original Ø50 spec**: radial engagement over the Ø20.5 hub aperture is
  11.75 mm/side (was 14.75) — still ample, and the mandatory 1.25 kN static proof is the
  release evidence either way. The disk edge (r22) still marginally overlaps the Ø50-PCD
  screw-head annulus, so the RH-100 subflush-head requirement stands.
- **On-arrival checks**: confirm austenitic stainless (barely/non-magnetic), check
  flatness (stamped part, no flatness guarantee — reject visible dish/burr), and **measure
  actual thickness**: the DIN 440 band is wide (±0.6), so set SP-100's cross-hole from the
  measured value (hole Z = measured t + 133.2; 4.0 nominal → Z137.2) before the spindle is
  machined. Washers arrive long before SP-100 is cut, so this costs nothing.
  **Measured 2026-08-01: t = 3.38 mm → cross-hole Z136.6** (recorded in the SP-100 section).
- Disk top seats at Z120.7, 2.5 ±0.5 mm below RH-100.
- The Ø50 disk edge crosses the Ø50 motor-screw PCD, so the RH-100 screw heads must be
  subflush. Measure the running gap to the lowest rotating screw or surface, not only the
  nominal hub underside.
- Retain with a DIN 935 M12 A4 castellated nut and an ISO 1234 3.2 × 32 A4 split pin through
  SP-100's Z137.2 cross-hole; the nut clamps KD-100 up against the Z120.7 shoulder. Full
  stack in "SP-100 bottom-end stack".
- Static proof the complete disk, nut, spindle, and plate path to 1.25 kN.
- There must be no normal-operation witness marks after maximum-speed and imbalance tests.

## BR-100 Hall bracket

> **Owner-fabbed, untracked (2026-08-02)**: hand-made by the owner; no design, material,
> or dimensions tracked here. The repo keeps only the interfaces it must satisfy: the
> MC-100 M3 hole pair (12 mm pitch at r71.25 on the standoff bisector — see MC-100), the
> PCB-02 mounting datums (electrical.md daughterboard section: M2 holes 6 mm apart,
> element 4.5 mm from H1, gap measured to the SOT-23 face, JST connector is the tallest
> rotor-facing feature and needs clearance + cable strain relief), and the sensing
> requirement — DRV5033 face-down over the r76 magnet track, gap qualified 1.5–4.0 mm
> (nominal 2.5 to hub top; magnet sits ~0.17 recessed → ~2.7 effective), set at fit-up
> and validated at TACH-01/02.

## Blade root-joint qualification (BA-00 deleted)

> **Status: PASSED 2026-08-14 (owner report).** MEC-01, MEC-02, and MEC-02B are complete;
> MEC-05 assembled rotor balance/runout remains separate.

> **No adapter exists anymore.** BA-00 (designed 2026-07-27) was deleted 2026-07-28 when
> BP-100 v3 integrated the mounting plate into the blade print ([blade-v2.md](blade-v2.md)):
> the blade root rectangle bolts straight to RH-100's stations with four M5 into nut pockets
> in the root, and printed Ø5 pins engage the hub's dowel holes. What survives here is the
> material research and the qualification program, retargeted at the **blade root print
> (segA)** — read "adapter" below as "blade root". Loads are small (blade centrifugal ~15 N
> at 170 RPM plus gravity moment); pins take shear, bolts clamp, no printed thread carries
> load. Filament for the loaded root is the owner's call (the aero/LW-PLA blade body vs the
> qualified CF-PPA below — segA material selection is part of the strength program).

- Qualified CF-PPA preferred; CF-PA12 only after equivalent testing.
- **Filament selection (researched 2026-07)**: primary **Bambu Lab PPA-CF** (true PPA + CF;
  168 MPa XY tensile, 208 MPa flexural, HDT 227 °C at 0.45 MPa, ~1.3% moisture saturation —
  about 66% lower than standard PA6-CF). The project printer is a Bambu **X2D**, which
  officially supports PPA-CF: its 300 °C nozzle runs the 280–310 °C band's lower-mid range
  (Bambu's own profile territory), and the 65 °C actively heated chamber directly helps the
  layer-adhesion/Z-strength concern that matters most for these parts. Procedure: dry 100–140 °C / 8–12 h before printing (never above 160 °C),
  print 280–310 °C nozzle / 100–120 °C bed / full enclosure / <100 mm/s on PEI; anneal
  120–140 °C for 6–12 h, but validate annealing on the actual adapter geometry in the
  production orientation first — Bambu warns some geometries warp or lose toughness.
  Backups: 3DXTech CarbonX CF-HTN (more chamber-forgiving) or Siraya Tech Fibreheart PPA-CF
  (easiest to print, lowest strength; confirm its annealing procedure from the TDS). CF-PA12
  only wins if every CF-PPA fails hot/humid conditioning.
- **Why qualification is empirical**: no vendor or literature data exists for year-scale
  creep, 10⁶-cycle fatigue of chopped-fiber filament, or Z-axis (layer-adhesion) strength —
  every TDS reports XY coupons only. Witness coupons must therefore be printed in the actual
  flat-on-hub-base production orientation, and the hot/humid sustained-load conditioning +
  fatigue matrix below is the release evidence, not datasheet numbers.
Qualification:

- Condition representative adapters using the filament supplier's hot/humid procedure while
  carrying the calculated sustained service load.
- Run at least 10⁶ combined centrifugal, bending, and torsion cycles at the documented
  maximum service-load envelope.
- Proof every installed adapter to 500 N radial; repeat after environmental and fatigue
  conditioning.
- Destructively test one representative from every material/process batch above 1.0 kN.
- Reject cracking, delamination, pitch change, hole elongation, or permanent set.
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

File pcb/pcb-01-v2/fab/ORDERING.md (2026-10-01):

# PCB-01 V2 JLCPCB ordering and final assembly

This file is the operator checklist for the generated PCB-01 V2 package. Regenerate the package
with `python3 pcb/tools/jlc_fab.py pcb-01-v2` immediately before upload. Do not reuse files from an
earlier board revision.

After the last regeneration, verify that the operator files still match the checked source:

```bash
cd pcb/pcb-01-v2
shasum -a 256 -c fab/release-manifest.sha256
```

## Upload files

- PCB fabrication: `pcb-01-v2-gerbers.zip`
- Assembly BOM: `bom-jlcpcb.csv`
- Component placement: `cpl-jlcpcb.csv`
- Attach `pofv-location-map.pdf`, `pofv-locations.csv`, and `impedance-requirements.csv` to the
  order, or send them to JLCPCB support against the order number before approval if the form has no
  attachment field.
- Keep `fabrication-notes.md`, `assembly-orientation.pdf`,
  `assembly-orientation-u13-u14.pdf`, `assembly-preview-3d.png`, `assembly-locator.pdf`, and this
  checklist open while reviewing the detected board and placement previews.

## Live order status
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

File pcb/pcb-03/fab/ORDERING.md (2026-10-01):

# PCB-03 JLCPCB bare-board and stencil order

Live order: `W2026090305011104`, five bare boards plus a top-side stencil, $17 shipped, submitted
2026-09-02. JLCPCB support confirmed they would add the supplied top-side paste layer.

On 2026-09-07, the authenticated order page showed this board/stencil order as **Shipped** by
Global Standard Direct Line. Michael confirmed receipt of the boards and stencil in the
procurement reconciliation conversation on **2026-09-30, America/Vancouver**, superseding
that shipping status. He dropped the optional e-ink addition; retain the boards, stencil,
display and design. The first-article gates below are deferred, with no new testing claimed.
DigiKey 101388939 entire-order cancellation was requested by email sent to orders@digikey.com
at 2026-10-01 01:41 UTC (September 30, 18:41 Vancouver), not vendor-confirmed. No J1/PHR-4
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

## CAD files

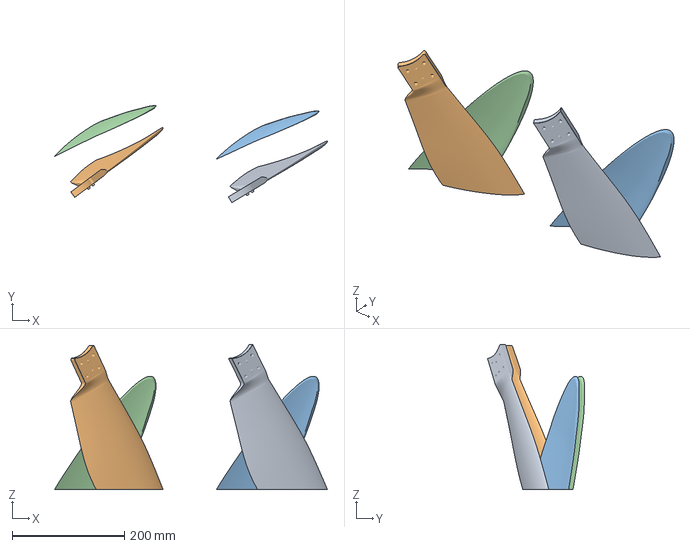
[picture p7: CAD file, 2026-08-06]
cad/BD-100 Project.3mf
486.1 x 172.8 x 258.6 mm
BD-100 segA x 2
BD-100 segB x 2

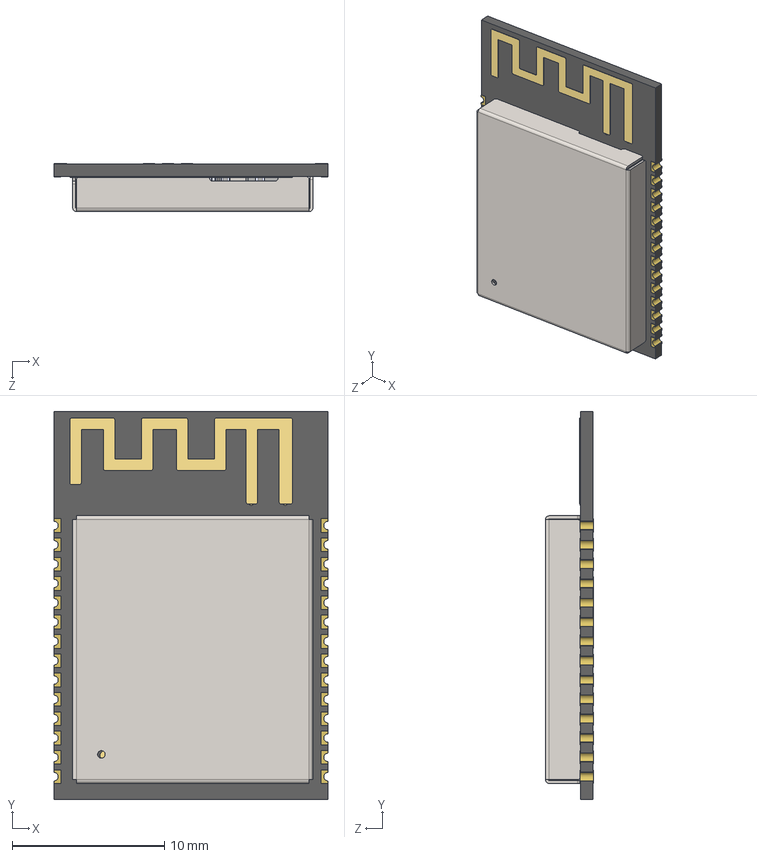
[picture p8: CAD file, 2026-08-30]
pcb/pcb-01-v2/3dmodels/ESP32-C6-WROOM-1.STEP
18.0 x 25.5 x 3.17 mm
uid__2428
MINI-ANT-TYPEB.STEP
R0201_20210301.xtd x 9
ESP32-C6_QFN40_5X5_202306.xtd
XTAL3225_20210301.xtd
SOP8_rev1_20210308.xtd
L0201_20210301.xtd x 2
DFN1006.xtd
C0402_20210301.xtd
C0201_20210301.xtd x 13
Imported
ESP32-WROOM-32D_shielding_case_

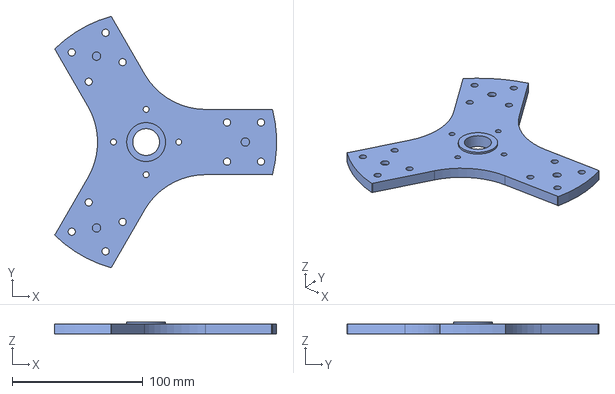
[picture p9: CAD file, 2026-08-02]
cad/RH-100_revA.step
170.1 x 192.8 x 9.50 mm

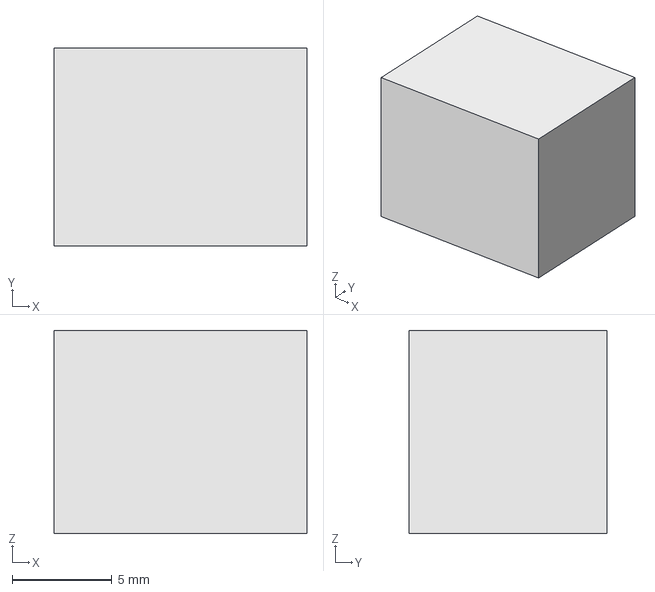
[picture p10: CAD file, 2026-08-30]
pcb/pcb-01-v2/3dmodels/J2_43650-0300_ENVELOPE.stp
12.6 x 9.90 x 10.2 mm

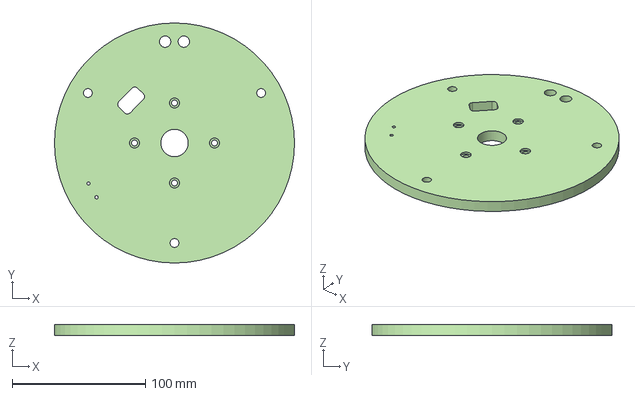
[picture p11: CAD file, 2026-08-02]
cad/MC-100_revA.step
180.0 x 180.0 x 8.00 mm

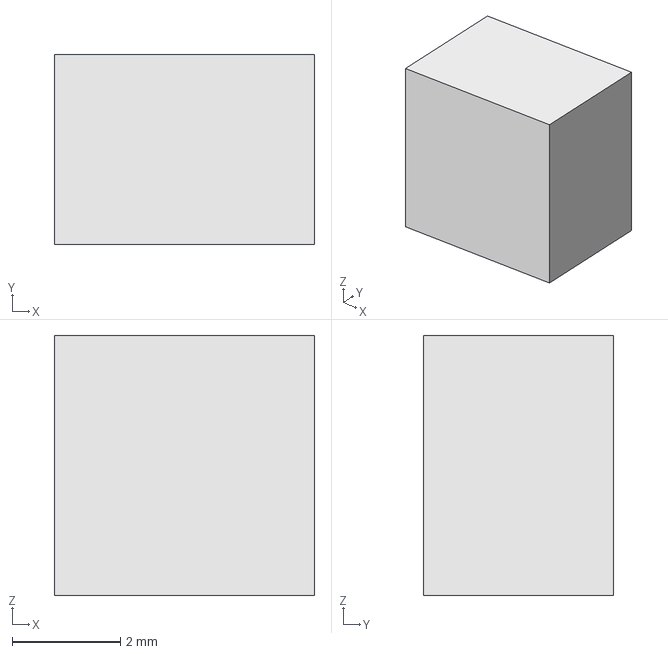
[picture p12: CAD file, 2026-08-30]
pcb/pcb-01-v2/3dmodels/RV1_3224W_ENVELOPE.stp
4.80 x 3.50 x 4.80 mm

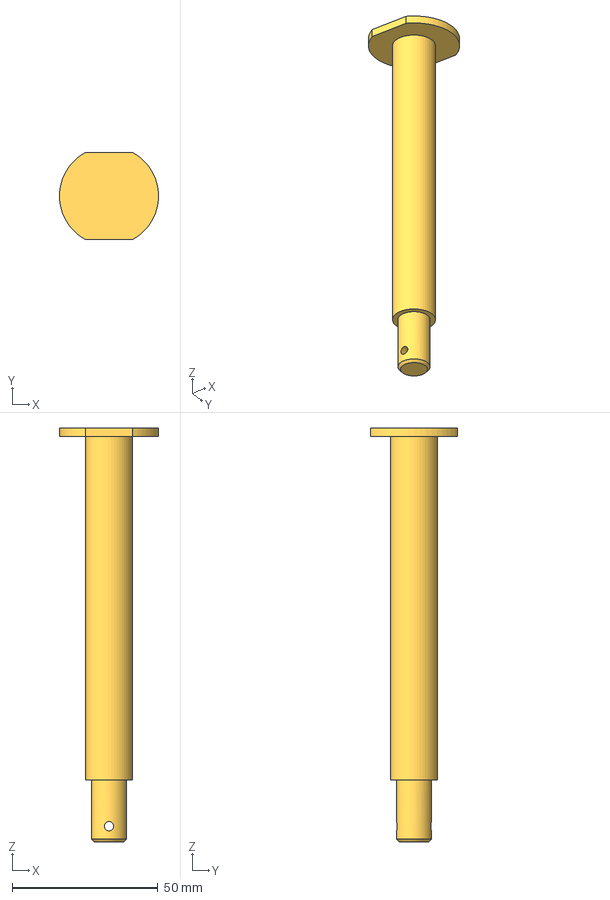
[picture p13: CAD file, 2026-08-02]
cad/SP-100_revA.step
34.0 x 30.0 x 142.0 mm

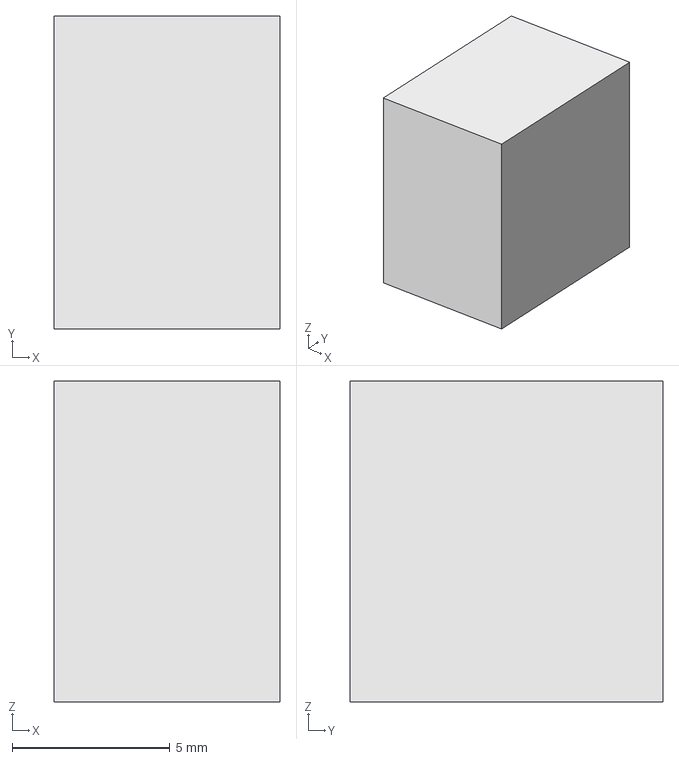
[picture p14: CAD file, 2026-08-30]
pcb/pcb-01-v2/3dmodels/J1_43045-0200_ENVELOPE.stp
7.15 x 9.91 x 10.2 mm

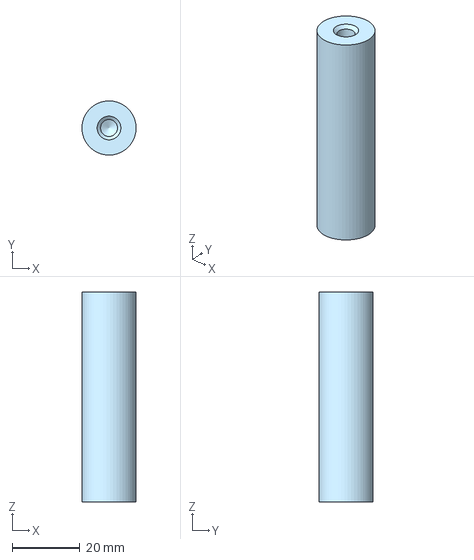
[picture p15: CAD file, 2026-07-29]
cad/ST-100_revA.step
16.0 x 16.0 x 62.0 mm

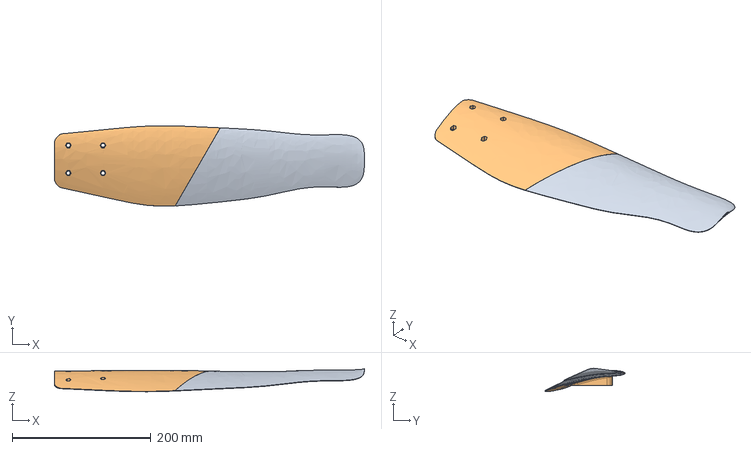
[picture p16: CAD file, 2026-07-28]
cad/BP-100.step
447.5 x 116.1 x 34.0 mm

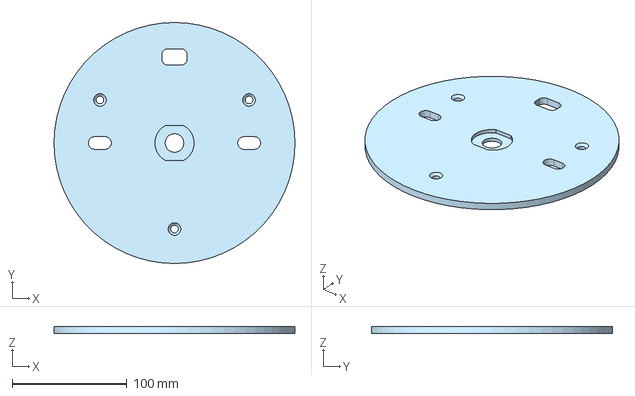
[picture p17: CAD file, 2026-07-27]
cad/MP-100_revA.step
210.0 x 210.0 x 6.00 mm

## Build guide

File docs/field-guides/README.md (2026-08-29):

# Integration field guides

`build_field_guides.py` generates the printable Stillair integration binder from the
canonical requirements in `docs/`, `testing/test-matrix.csv`, and the KiCad board files.

```bash
UV_CACHE_DIR=/tmp/stillair-uv-cache uv run --with reportlab \
  python3 docs/field-guides/build_field_guides.py
```

The generated PDF is written to
`output/pdf/stillair-integration-field-guides.pdf`.

For a concise PCB-01 rebuild handout with only the manually installed parts and the removable
installed-tuning leads, run:

```bash
UV_CACHE_DIR=/tmp/stillair-uv-cache uv run --with reportlab \
  python3 docs/field-guides/build_pcb01_rebuild_booklet.py
```

This writes `output/pdf/pcb01-rebuild-and-tuning-leads.pdf`. Print it two-sided on the long edge.

For the one-page switched wiring map from PCB-01 J7 to the DSD TECH SH-U09C2 adapter, run:

```bash
UV_CACHE_DIR=/tmp/stillair-uv-cache uv run --with reportlab \
  python3 docs/field-guides/build_j7_usb_uart_guide.py
```

This writes `output/pdf/pcb-01-j7-usb-uart.pdf`. It includes normally-open BOOT/RESET switches,
the removable RTS automated-boot branch, manual fallback, and monochrome line patterns. Print it
one-sided in landscape orientation.

The sheets are intentionally concise. They complement, rather than replace, the detailed
requirements and vendor procedures. A `HOLD` badge means the guide records the boundary but
does not authorize work beyond it.

The PCB population pages use top/component-side target renders exported from KiCad and kept
in `docs/field-guides/assets/`. They are placement aids, not photographs of an already-built
board. Refresh them whenever either PCB layout changes, and re-check every callout against the
position export before printing.

For the fine-pitch techniques used on sheets 1A and 1B, see the curated
[SMD soldering video references](soldering-videos.md).

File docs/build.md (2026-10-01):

# Build release

Order, assemble, prove, install. A gated sequence built around an instrumented custom V1
board. No TI evaluation module is required. Final loaded work happens on the installed plate,
beginning at the lowest useful speed with continuous observation and a reachable cutoff.

## Current remaining work (owner confirmation, 2026-09-30)

Michael's latest status in the procurement reconciliation conversation (America/Vancouver)
is final tuning, followed by the aesthetic housing including the integrated Hall sensor
holder and sound dampening cover. The Hall harness is built and done. This supersedes
interim V2 installation as the primary pending step; it does not claim new commissioning
or change the historical [September 27 bench evidence](../testing/pcb-01-v2-bench-2026-09-27.md).
Retain the qualification criteria below and the [housing requirements](housing.md).

## Build sequence (five gated phases, historical plan)

1. **Build and bring up PCB V1** — buy the GL100 and order the roomy 78 × 58 mm V1 board.
   Verify rails and DRVOFF first, then measure the motor and tune sensorless startup through
   I²C using the board's test points.
2. **Freeze CAD and PCB V2** — use measured V1 results to freeze the blade, hub,
   capture spindle, carrier, plate, housing, protection, thermal design, and golden MCF
   register set. Keep the PCB outline unchanged.
3. **Fabricate and inspect** — make the metal and printed parts, inspect every critical
   interface, destructively test a blade root-joint sample, proof the three installed blade
   roots, and prepare four matched blades.
4. **Assemble and inspect unpowered** — install the final mechanics, verify retention and hand
   clearance, and check balance and runout before applying motor power.
5. **Ceiling integration and commissioning** — the earlier plan covered mounting and routing
   24 V, motor, Hall, and long-USB service connections on the installed plate. Current remaining
   work follows the owner status above. Loaded MPET, tuning, representative starts,
   normal-range speed and shutdown checks, and thermal verification then run in that final
   support/load/acoustic environment.

### Replacement PCB-01 V1 service path (historical, 2026-08-28)

The replacement board passed hand-populated C34/U8 continuity and initial 18 V rail checks, but
its native USB never enumerated after known cables, forced ROM boot, host restart, and J6 pin
reflow. UART0 on J7 is the recovery path through a DSD TECH SH-U09C2 FT232RNL USB-UART adapter.
Solder one light lead to each J7 pin 2--6 and leave J7.1/board-3V3 isolated. A/B/C connect TX,
RX, and AGND to adapter RXD, TXD, and GND. D/BOOT branches to adapter RTS and to a normally-open
momentary switch whose other terminal returns to C/AGND. E/EN uses the same switch-to-C pattern
for manual reset. Disconnect D from RTS before using the BOOT switch; never ground an actively
driven RTS output. Check every intended connection and adjacent-pad isolation before power.

At the time of this V1 investigation, the application defaulted to the J7 UART0 console while a
`usb-console` build feature retained native USB. The synchronized runner could assert active-low
RTS, cold-cycle
the Kasa supply, release BOOT, flash with `--before no-reset`, and watchdog-reset into the UART
application. This sequence is host-tested but not yet physically qualified; see
[controls.md](controls.md#commissioning-interface-and-build-policy).
The printable direct end-to-end pad map is
[`pcb-01-j7-usb-uart.pdf`](../output/pdf/pcb-01-j7-usb-uart.pdf).

PCB-01 V2 does not use this harness. V2 has native USB-C at J4 with manual BOOT and RESET switches;
normal 24 V board power is required because USB VBUS is not connected to the power tree. Hold BOOT,
tap RESET, release BOOT, then flash through J4.

## Mount build-first plan (2026-07 review; supports incremental in-person building)

- **Mock first, cheap**: an MDF or 3D-printed Ø210 disk + three printed/threaded-rod
  Ø16 × 62 standoffs + a blank Ø180 disk, to feel the (now much shallower) drop in the room
  before any stainless is cut.
- **Received + owner-accepted 2026-08-14**: MP-100, ST-100 (qty 4),
  SP-100, MC-100, RH-100, PCB-01 (2 assembled + 3 bare), and PCB-02 (5 bare).
- **Ordered finished**: MP-100 (JLCCNC 2026-07-27), ST-100 (JLCCNC 2026-07-28, qty 4,
  clear anodized), KD-100 (became a purchased DIN 440 washer — Accu 2026-07-28). BP-100
  blade manufacturing and blade-root qualification passed 2026-08-14; assembled rotor
  balance/runout is checked unpowered during final ceiling integration.
- **SP-100 measure-first gates closed before fabrication**: measured KD-100 thickness set
  the cotter-hole Z; measured GL100 axial length set the capture stack. The finished part
  arrived with the rest of the JLCCNC batch on 2026-08-14. See parts.md > SP-100.
- **MP-100 is released** (2026-07-27): both paper decisions landed — ENC tab clocking at
  45/105/165/225/285/345° and a 15° rim cable entry replacing the deleted mid-plate slot.
  See parts.md "ENC-100 tab clocking" and "Cable entry". Never was motor-gated.
- **MC-100/RH-100 partial strategy**: their motor-independent features (ODs, standoff
  holes, center clearances, tether holes, blade-root stations, tach pockets) can be machined
  early, leaving the motor-pattern operations (Ø60/Ø50 PCD clocking, wire window, pilot OD)
  as final ops after the GL100 is measured.

## Procurement gates

- **Buy first**: CubeMars GL100 KV10, GST60A24 supply, and the fully populated 78 × 58 mm
  PCB V1. The TI evaluation board is intentionally skipped.
- **After V1 pass**: controller V2. Same outline and holes; remove only development features
  proven unnecessary after startup, thermal, and essential safety testing.
- **After CAD review**: custom mechanics. Fabricate plate, carrier, hub, capture hardware,
  blades, and housing only after motor faces, fastener depths, and the slab
  interface are resolved.

Purchase state is tracked in [../bom/bom.csv](../bom/bom.csv).

## Commissioning

Pass or fail, not "seems fine." The full matrix with method, acceptance limit, and sign-off
fields is [../testing/test-matrix.csv](../testing/test-matrix.csv); these limits are the
minimum release basis and can be tightened after measured data exists. Highlights:

| Test | Acceptance limit |
|---|---|
| Representative starts (20/direction at the intended minimum at 24.0 V; 5/direction at 23.3 and 24.7 V) | No retry, reverse kick, stall, click, or hunting |
| Speed range (steady at 30/40/55/70/120/170 RPM) | Stable speed and acceptable current waveform; each low speed released only if all starts pass |
| Hard limit (max command + command-path fault) | Motor controller never exceeds 180 RPM |
| Rotor proof (secured external drive, 216 RPM × 2 min/direction, continuously observed) | No abnormal motion, sound, damage, loosening, deformation, balance shift, or contact |
| Bus voltage (≥100 MHz probe at MCF pins during coast/cutoff/stall/reversal) | Peak ≤35 V, no 28 V OVP trip; otherwise redesign suppression |
| Analog overspeed | Reset near 180 RPM; trip near 200 RPM, never above 220 RPM across voltage and temperature |
| Essential fault behavior | Hardware fault or watchdog disables the bridge; power returns off; reversal only after stop |

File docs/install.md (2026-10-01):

# Installation

> **Current owner status, 2026-09-30 America/Vancouver:** final tuning remains, followed by
> the aesthetic housing with integrated Hall sensor holder and sound dampening cover.
> The Hall harness is built and done. Source: Michael's procurement reconciliation
> conversation. Earlier installation and test evidence below is preserved; no new tests
> are claimed. MP-100 installation, tether proof, and catcher proof remain accepted complete.

Site: 11-storey concrete condo, ceiling slab possibly post-tensioned (treat as PT until
proven otherwise); existing bolts of unknown type in the slab. Anchor engineering basis:
ICC-ES ESR-2713 (Simpson Titen HD), design strengths in cracked concrete at f'c 2500 psi —
the correct conservative assumption for a suspended slab soffit.

**Site status 2026-08-20:** MP-100 is installed on the ceiling (owner report), with all three
ST-100 standoffs and SP-100 spindle in place. The two primary holes and primary plate mount
are complete. `INS-01` is accepted as passed against the documented anchor and spacer stack.
The ceiling feed has been verified at a stable 24 V with correct polarity. No further anchor,
plate, tether, or catcher proof is required. Keep the feed de-energized through the remaining
mechanical assembly, cable support, hand-clearance, and installed continuity checks.

**Stationary-stack status 2026-08-20:** GL100 is installed on MC-100 with four M4 × 12 screws,
blue removable threadlocker, and an approximately 1.5 N·m hand-torque target. MC-100 is mounted
to all three ST-100s with M6 × 20 A4-80 screws, glued Nord-Lock pairs, no threadlocker, and the
selected 5 N·m target.

**Hall-bracket result:** Michael installed BR-100 after the hub and blades so the physical
magnet-to-sensor gap could be set directly. The installed Hall assembly is owner-accepted
complete against the qualified 1.5–4.0 mm sensing window.

**Installed status 2026-08-20:** Michael reports RH-100 and all blades installed after resolving
the blade-fastener fit-up, plus BR-100/PCB-02, the Hall magnet, both balance slugs, and PCB-01.
PCB-01 has its 24 V, Hall, and motor harnesses connected. Michael subsequently reported the
KD-100/castellated-nut/cotter stack complete after receiving the anti-seize, 20 N·m, tighten-only
to alignment, and new-cotter procedure. He accepted the complete installation, blade-fastener
resolution, clearances, cable support, continuity/polarity, connector seating, and hand rotation
as done on 2026-08-20. Loaded tuning is next.

## Active remaining integration

Mechanical installation and its unpowered checks are complete by owner report. Preserve this
installed state and proceed through the loaded commissioning sequence in `integration.md`.

Loaded MPET and tuning follow this installation as a separate commissioning step. The installed
ceiling position is the selected loaded-test location because it provides the final mechanical
support, rotor load, cable lengths, ceiling interaction, and room acoustics. The USB oscilloscope
is optional additional evidence if available; its safe hookups are in
[`observability.md`](observability.md).

**Historical tether note:** the original MP-100 clearance at X0, Y-82 was only
sqrt(65^2 + 82^2) = 104.6 mm from either primary center, conflicting with the documented
>=190 mm basis. Michael resolved and tested the final tether arrangement outside the active
project plan. Its location and termination are not managed here.

## Anchor selection

Demand per primary anchor (two on 130 mm centers, from the design envelope of 1.25 kN
vertical / 0.30 kN lateral / 60 N·m overturning / 8 N·m torque): ~1.09 kN tension,
~0.21 kN shear. True sustained dead tension is only ~25–40 N per anchor for a 5–8 kg
assembly. Tether requirement: the calculated dynamic catch peak with ≥2× margin (order
1–2 kN for the ~4–5 kg retained mass over 15–20 mm slack — see parts.md).

- **Primary anchors: 2× Simpson Titen HD 3/8 × 3 in (`THD37300H`)** — design tension
  3.57 kN cracked (pullout-governed) vs 1.09 kN demand = **3.3× margin**; 70 mm drilled
  hole; min slab 102 mm; 130 mm centers clear the 76 mm minimum spacing; reaches full
  embedment through plate + 3 mm spacer with 3.7 mm to spare. Heavy flat washers over the
  11 × 20 mm slots. Install per Simpson's instructions (drill per ESR, socket/impact
  drive — screw anchors have no set torque like wedge anchors).
- **Tether anchor: Titen HD 3/8 × 4 in (`THD37400H`)** — 7.81 kN, covering both load bases
  unconditionally; 89 mm hole; min slab 127 mm. **Simplification path**: if the
  calculated/tested catch peak is ≤ ~1.7 kN, a third `THD37300H` (3.57 kN, ≥2× margin)
  covers it and all three anchors become one part at one 70 mm hole depth. Keep ≥190 mm
  from the primaries; terminate in a forged shoulder eyebolt or rated eye nut (never a
  bent-wire eye); proof-test in place.
- **Service rule**: Titen HDs are torqued once and never fully removed (ESR-2713 §4.3
  permits a one-turn backout only; screw-formed concrete threads are a consumable
  interface). The design already services at the carrier-to-standoff M6 joint from below —
  the anchors and plate stay on the ceiling.
- **Tether termination (historical options)**: a rated pad-eye under the THD37400H head or
  a Titen HD rod-hanger with a forged 3/8-16 shoulder eyebolt were the documented options.
  Final selection and installation are owner-managed.

## Mounting sequence

Titen HDs are through-fixture fasteners — the plate and anchors go up together (the screw
head + washer clamps the plate; there is no set-stud-first step as with wedge anchors):

1. **Bench-assemble everything that needs ceiling-face access**:

   - Put MP-100 ceiling-face-up. Insert SP-100 (the center capture spindle) from that side,
     seat its flange fully in the double-D recess with metal bearing directly on the pocket
     shoulder, and leave the long shank hanging down. It cannot be added after anchoring.
   - Add three tiny, spaced dots of non-corrosive neutral-cure RTV across the ceiling-side
     perimeter seam between the seated flange and MP-100. Do not put silicone under the
     flange or on its structural bearing face. Cure fully in air per the product instructions,
     then tap/shake the unit to confirm there is no metallic click. The RTV is removable
     anti-rattle restraint only; capture loads remain metal-on-metal through the shoulder.
   - Install three ST-100 standoffs with three M6 × 16 A4 flat-head screws inserted from the
     ceiling face. The fourth standoff is a spare. Tighten to the released joint requirement;
     verify each countersunk head is flush or slightly below the ceiling face.
   - Keep the unit ceiling-face-up until the RTV cures; flipping the plate can release
     SP-100 before then. The hard spacers leave clearance above MP-100, so the slab does not
     directly clamp the flange after installation.
   - Do not add MC-100/motor, rotor, catcher nut stack, electronics, cable clamps, or housing
     yet. All remain accessible from below and only make the overhead lift heavier.

2. Mark the two primary drill spots via the plate or the PLA template (the 11 × 20 slots
   absorb ±4–5 mm). Tether work is outside this archived sequence.
   Drill **without the plate** using a 3/8 in carbide bit meeting ANSI B212.15 (bit nominal
   matches the anchor — never substitute a 10 mm metric bit, the thread engagement assumes
   ANSI tolerance), depth-stopped at ~75 mm (primaries) /
   ~95–100 mm (tether), then brush/blow clean per Simpson's instructions. Tooling: M12 Fuel
   hammer drill (3404) in hammer mode with a **straight-shank** ANSI B212.15 carbide
   percussion bit — Makita B-68812 3/8 × 6 in (verify ANSI marking and ≥100 mm flute length
   on arrival). This is the straight-shank option for the 3404's 3-jaw chuck. If renting an
   SDS-plus rotary hammer instead, use an ANSI B212.15 SDS-plus bit; SDS bits do not fit the
   3404. Expect slow going in tower slab:
   peck-drill to clear dust and cool the tip; if a hole barely progresses, rent an SDS-plus
   rotary hammer instead of forcing it. The M12 impact driver (no axial percussion — cannot
   drill) **drives** the anchors via a 9/16 in socket.
3. Offer up the plate unit. At each primary location, place the loose hard-spacer washer
   between MP-100 and the ceiling, then drive the Titen HD through its room-side washer and
   plate slot (stack: head -> washer -> plate -> hard spacer -> ceiling). The spacers are
   added during the lift, not attached during bench assembly.
   **Length/stack budget**: the 3 in screws have 12.7 mm of fixture budget above the
   63.5 mm minimum embedment — plate 6 mm leaves ≤6.7 mm for washer + spacers combined.
   Use standard-thickness washers (~2.5 mm) and only as much spacer as the finish demands
   (≤~4 mm); if more shimming is needed, step up to a 3-1/2 in screw rather than thinning
   the embedment. Hardware: Prime-Line 9080006 USS 3/8 × 1 in OD zinc washers — one under
   each head, one as the hard spacer per anchor (2.5 mm covers the ~1–2 mm ceiling texture
   plus any slightly-proud countersunk M6 heads on the plate's ceiling face); stack =
   11 mm of the 12.7 mm budget. Drill ~75 mm for the primaries, ~95–100 mm for the 4 in
   tether ("too deep" costs nothing; too-shallow driving stalls the screw proud of the
   plate).
4. Stack from below: carrier (motor pre-bolted, wires through the window) onto the
   standoffs (M6 × 20 + wedge washers), hub + rotor onto the motor face, KD-100 +
   castellated nut + cotter onto the spindle (no counter-hold needed — the double-D pocket
   keys the spindle; rotate the *nut* to align a castellation with the cotter hole), then
   electronics and housing. Service
   reverses this from below; anchors are never touched.

## Sources

ESR-2713 (icc-es.org) · Simpson Titen HD installation instructions.

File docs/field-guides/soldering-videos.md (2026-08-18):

# SMD soldering video references

These videos support the hand-population maps on sheets 1A and 1B of the printable field
guide. The board maps remain authoritative for component identity, orientation, and order.
The videos are for learning the hand technique.

## Short watch list

1. [EEVblog #997: How To Solder Surface Mount Components, 17:37](https://www.youtube.com/watch?v=hoLf8gvvXXU)
   is the main overview. The practical drag/dab demonstration starts around 3:36 and covers
   the basic iron-and-wire approach used throughout this build.
2. [PACE: Fine Pitch QFP Install with MiniWave Tip, 2:30](https://www.youtube.com/watch?v=jJescBRDyMQ)
   is a close-up of the tack-and-drag motion. Focus on aligning the package, tacking
   opposite corners, adding flux, keeping pressure off the leads, and drawing the solder
   bead along a row. The package shown has four rows; U8 is easier because it has only two.
3. [Hand soldering 0603 components, 4:00](https://www.youtube.com/watch?v=fqHleZjTaH8)
   is the relevant one-pad-tack demonstration for PCB-02 C1. The same method applies to
   PCB-01 C34, even though C34 is physically larger and bridges an undersized footprint.

## Map the techniques to these boards

- **PCB-01 U8 (SOIC-14):** use an iron, flux, and thin solder wire. Align pin 1, tack one
  corner, recheck every lead over its pad, then tack the diagonally opposite corner. Flux
  both rows and drag-solder them. Remove bridges with fresh flux and solder wick.
- **PCB-01 C34 (1206 over a 0603 site):** tin one pad lightly, hold the part in position,
  reheat that pad to tack it, then solder the other end. Return to the first end only if its
  joint needs refreshing.
- **PCB-02 C1 and U1 (0603 and SOT-23):** use a fine iron tip, thin solder wire, and flux.
  Tack one pad or lead, align the part, then solder the remaining pads. Reflow the tack last
  if it needs more solder or a cleaner fillet.
- **Bridge cleanup:** add flux, lay clean wick over the bridge, touch the iron to the wick,
  and lift iron and wick together as soon as solder flows. Do not scrub or pull on a cold
  joint.

The right-angle through-hole connectors and radial capacitors use ordinary through-hole
soldering, so they are intentionally not covered here. Paste, a stencil, and hot air are
also unnecessary for this build plan.

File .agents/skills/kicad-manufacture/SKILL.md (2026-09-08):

---
name: kicad-manufacture
description: "Generate and validate downstream KiCad fabrication outputs for a Stillair board. Use for Gerbers, drill, JLCPCB, BOM/CPL, assembly files, production export, or ordering."
---

# KiCad fabrication

Fabrication begins only after the `$pcb` routed-KiCad review passes. For a tscircuit-first board,
also require current source-to-KiCad parity and every required `design/kicad-augment.json` item to
be implemented and verified.

Use `python3 pcb/tools/jlc_fab.py <board>` from the repository root. The board profile in that script
defines expected layers, assembly mode, DNP/no-part/hand-solder sets, LCSC policy, and output path.
Add or review a board profile rather than copying the script. Keep board-specific exceptions narrow
and documented.

Before export:

- save the KiCad project and refill zones;
- run the board's ERC/DRC path and account for only exact reviewed waivers;
- confirm zero unconnected items;
- verify outline, drills, stackup/copper, impedance requirements, mask/paste exceptions, special
  vias, critical orientations, and component side;
- verify the configured Gerber layer set and assembly split against the current order contract.

After export, inspect the archive contents, drill tool table, board/copper renders, BOM/CPL, and
release manifest. The fab house's live quote and DFM output are authority for current capabilities
and prices. Recheck current rules before ordering; do not use retained generic minimum tables as a
substitute.

Do not use Konnect's manufacturing package or validator. They have produced structurally wrong
outputs and false-ready reports on these KiCad 10 projects. `kicad-cli`, the project scripts, and
artifact inspection are the release path.

On the JLCPCB order page, confirm placement for every assembled design, check pin 1 and polarity in
the preview, and review returned CAM/engineering output against the board's ordering document before
approval.

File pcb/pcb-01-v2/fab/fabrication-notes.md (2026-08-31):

# PCB-01 V2 fabrication notes

These requirements are not conveyed reliably by Gerber and Excellon alone. Paste the three quoted
requirements into the JLCPCB order remarks and require production-file confirmation before approval.

> POFV REQUIRED: Epoxy-fill and copper-cap the twelve 0.30 mm plated holes inside U1 exposed pad
> 41. Treat only the coordinates in pofv-locations.csv and pofv-location-map.pdf as POFV, even
> though Excellon calls them T2 ComponentDrill. The attachments state both KiCad top-view and
> Excellon signed coordinates. Keep U1 pad 41's submitted top solder-mask aperture open for
> soldering; add no separate bottom apertures. Do not leave resin exposed.

> U3 PADS 4/5 ARE SOLDER-MASK-DEFINED: Preserve the submitted 0.08 mm mask overlap on all sides.
> Do not convert pads 4/5 to NSMD or expand their mask apertures during CAM.

> USB IMPEDANCE: Hold 97 ohm differential on both via-free F.Cu USB sections, `USB_DP`/`USB_DN`
> from J4 through U13 to R58/R59 and `USB_D_MCU_P`/`USB_D_MCU_N` from R58/R59 to U2. Both use
> 0.20 mm track width and 0.20 mm pair gap. The worst plug-orientation path skew is 1.80 mm;
> the MCU-side skew is 0.01 mm. The USB-C duplicate-contact breakout is artwork-defined and must
> not be reshaped in CAM. JLC's live coated,
> non-coplanar calculator gives 96.85 ohm for this geometry, inside the USB 2.0 90 ohm +/-15%
> range. See impedance-requirements.csv and confirm the 97 ohm target in CAM before release.

Order and production-file checks:

- 88 x 64 mm, four layers, 1.6 mm, 2 oz outer copper, 1 oz inner copper, ENIG.
- FR-4 Tg >= 150 C, green solder mask, white silkscreen.
- Impedance-controlled JLC041621-7628 stack: 0.070 mm F.Cu / 0.203 mm 7628 prepreg
  (Er 4.4) / 0.030 mm In1 / 1.030 mm FR-4 core / 0.030 mm In2 / 0.203 mm 7628
  prepreg / 0.070 mm B.Cu. This is JLC's live 4-layer, 1.6 mm, 2 oz outer, 1 oz inner result.
- Select epoxy-filled and capped vias, attach pofv-location-map.pdf and pofv-locations.csv, and
  repeat in the order remarks that the request applies to these twelve pad holes. The ordinary via
  finish selector alone does not control component pad holes.
- Standard PCBA, top side only. Use bom-jlcpcb.csv and cpl-jlcpcb.csv.
- Confirm every U1 POFV coordinate, both U3 SMD mask apertures, and the 97 ohm differential USB
  requirement in JLC's production files.
- Do not approve manufacturing until routing is complete, zones are refilled, DRC has zero
  unconnected items, and a fresh non-assembly-only package has been generated.

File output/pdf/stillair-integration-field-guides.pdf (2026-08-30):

0A Active Integration Map | FIELD GUIDE

# YOU ARE HERE

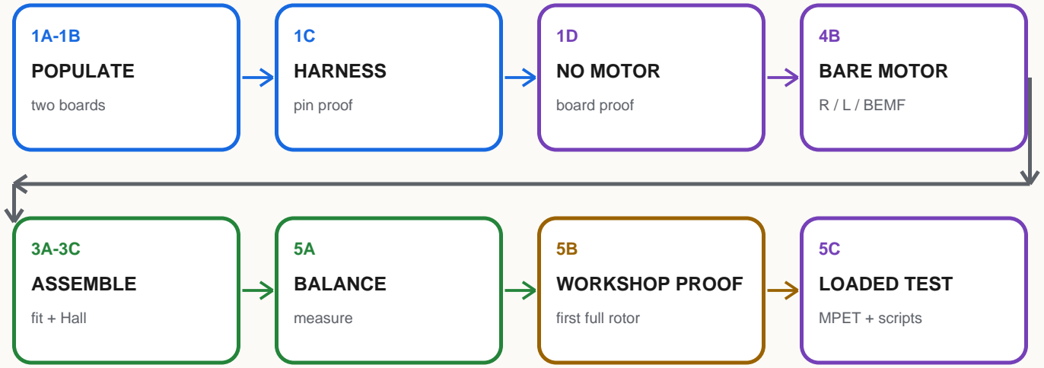
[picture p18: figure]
POPULATE; two boards; HARNESS; pin proof; NO MOTOR; board proof; BARE MOTOR; R / L / BEMF; ASSEMBLE; fit + Hall; BALANCE; measure; WORKSHOP PROOF; first full rotor; LOADED TEST; MPET + scripts

## WHAT COUNTS AS DONE

A result is measured and recorded, not just observed. | A failed gate stops the next powered stage.
Connector polarity and pin order are proved end-to-end. | After loaded MPET, verify config before start/speed qualification.
Installed unpowered checks precede gradual loaded work. | Normal safety firmware + long USB J6; cutoff outside sweep.

## BOUNDARIES KEPT OUT OF THIS ACTIVE BINDER

Michael performs installed work with one-step-at-a-time project guidance. Completed plate, tether, and catcher work stays closed. Deferred scope remains omitted unless explicitly reopened.

STOP / HANDOFF Start at 1A. Carry only the current sheet, board, and required tools to the bench.

SOURCE: docs/STATE.md; docs/integration.md; testing/test-matrix.csv PAGE 1

1A PCB-01 Population Map | FIELD GUIDE

TOP / COMPONENT SIDE - KiCad target appearance

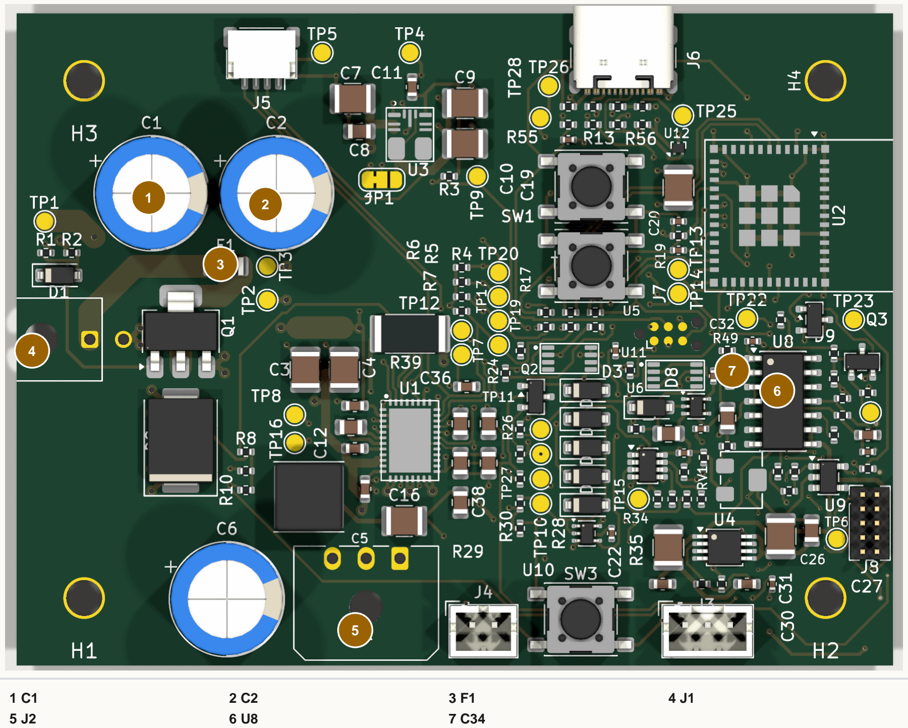
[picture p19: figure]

SOLDER ORDER: U8 -> C34 -> J1/J2 -> C1/C2 -> INSPECT -> F1 LAST 1 + 2 C1 / C2
EEU-FR1H471, 470 uF 50 V. Positive lead to board +; negative stripe to pin 2 / PGND. Seat square without crushing bung.

### 3 F1 - INSTALL LAST

Low-profile tinned copper link across the 1206 pads. Near-zero ohms after soldering. External wall-side 3 A fuse remains mandatory.

4 + 5 CONNECTORS
J1 43045-0200; J2 43650-0300. Larger chisel tip. Tack one electrical pin, square and fully seat housing, then finish. Locating pegs are not soldered.

### 6 U8 / 7 C34

U8 LM2907M/NOPB: notch/dimple to pin-1 marker, tack pin 1 then diagonal pin 8, flux and drag-solder. C34 C1206C104K3GACTU: 100 nF C0G 25 V +/-10%, spanning the smaller 0603 site, not shorting it.

PCB-01: USE THE IRON, NOT BROAD HOT AIR. Then clean and dry; inspect under the microscope; verify no hard short from RAW24, VM24, 3V3, or 12V_TACH to ground; photograph the board.

SOURCE: pcb/pcb-01/pcb-01.kicad_pcb; bom/bom.csv; docs/electrical.md, SCH-06 PAGE 2

1B PCB-02 Population + Soldering | FIELD GUIDE

TOP / MAGNET-FACING COMPONENT SIDE - KiCad target appearance

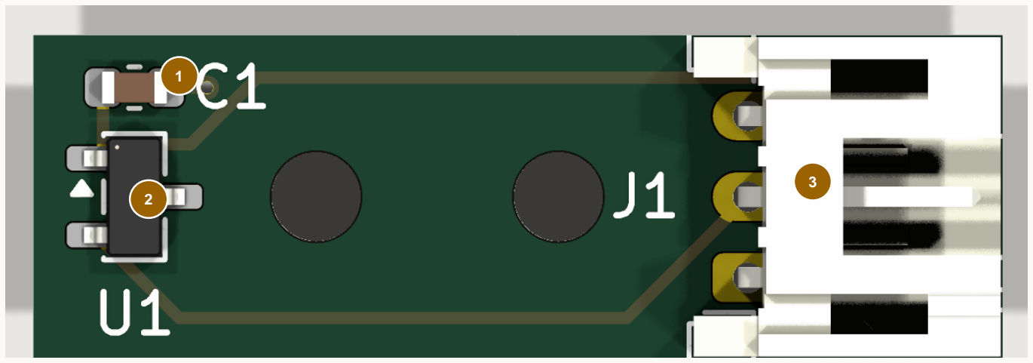
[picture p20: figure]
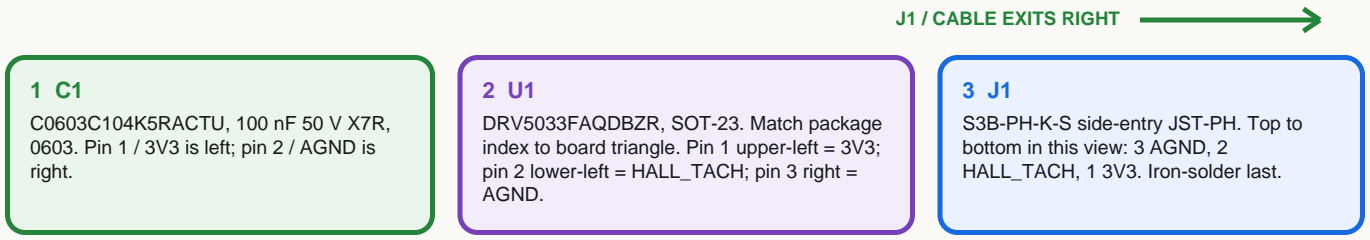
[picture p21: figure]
J1 / CABLE EXITS RIGHT; C0603C104K5RACTU, 100 nF 50 V X7R,; right.; DRV5033FAQDBZR, SOT-23. Match package; AGND.; S3B-PH-K-S side-entry JST-PH. Top to bottom in this view: 3 AGND, 2 HALL_TACH, 1 3V3. Iron-solder last.

0603. Pin 1 / 3V3 is left; pin 2 / AGND is

index to board triangle. Pin 1 upper-left = 3V3; pin 2 lower-left = HALL_TACH; pin 3 right =

## IRON METHOD: THIN SOLDER WIRE + FLUX

Flux + tin one pad | Place under
microscope | Reheat to tack | Solder remaining pads

Inspect + wick
bridges | Iron-solder J1

C1 - ONE-PAD TACK
Tin one pad lightly. Reheat it while placing C1, align the body, then solder the other end. Refresh the tack only if needed.

U1 - THREE LEADS
Flux, tack pin 3, correct alignment, then solder pins 1 and 2. Reflow the tack last if it needs a cleaner fillet.

J1 - LAST
Tack one pin, reheat while seating the body square and flush, finish the other pins, then revisit the tack.

## FINAL INSPECTION

All parts on magnet-facing side; sensor marked face will face magnet. Do not use magnet polarity as the orientation cue.

No short: 3V3 to HALL_TACH, 3V3 to AGND, or HALL_TACH to AGND.
Flux cleaned using its specified method; board completely dry. | Microscope: wet fillets, no lifted lead, whisker, ball, or disturbed part; photograph board.
STOP / HANDOFF | PCB-02 passes magnified inspection and unpowered three-net short checks. Do not power yet.

SOURCE: pcb/pcb-02/pcb-02.kicad_pcb; bom/bom.csv; docs/electrical.md, Hall daughterboard PAGE 3

# 1C Harness Build + Pin Proof

FIELD GUIDE

## LOOK INTO THE MATING FACE; USE MOLDED PIN-1 MARKS, NOT WIRE COLOR MEMORY

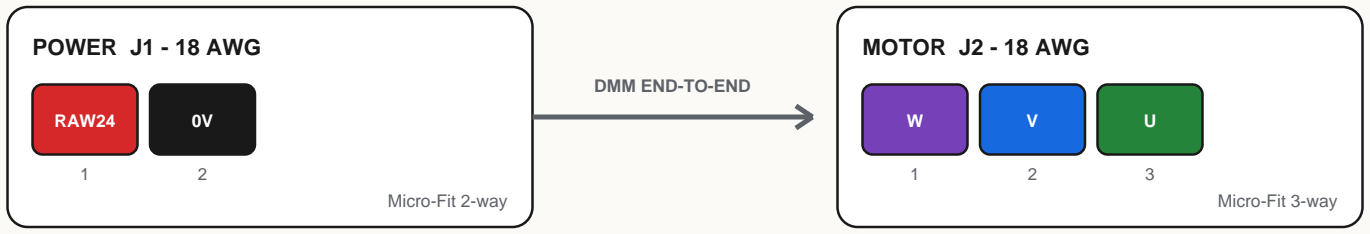
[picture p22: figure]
POWER J1 - 18 AWG; RAW24; Micro-Fit 2-way; MOTOR J2 - 18 AWG; Micro-Fit 3-way; DMM END-TO-END
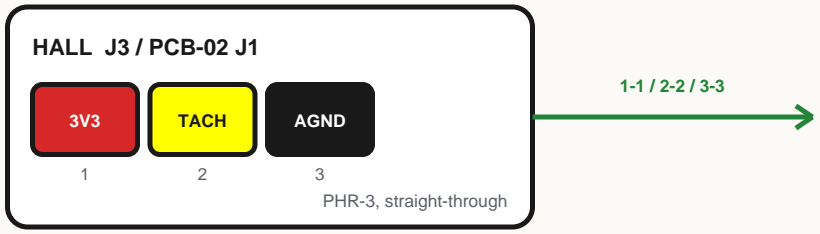
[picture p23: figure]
HALL J3 / PCB-02 J1; TACH; AGND; 3 PHR-3, straight-through

PROGRAM J7

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
BOOT

5

GND

6
do not drive 3V3

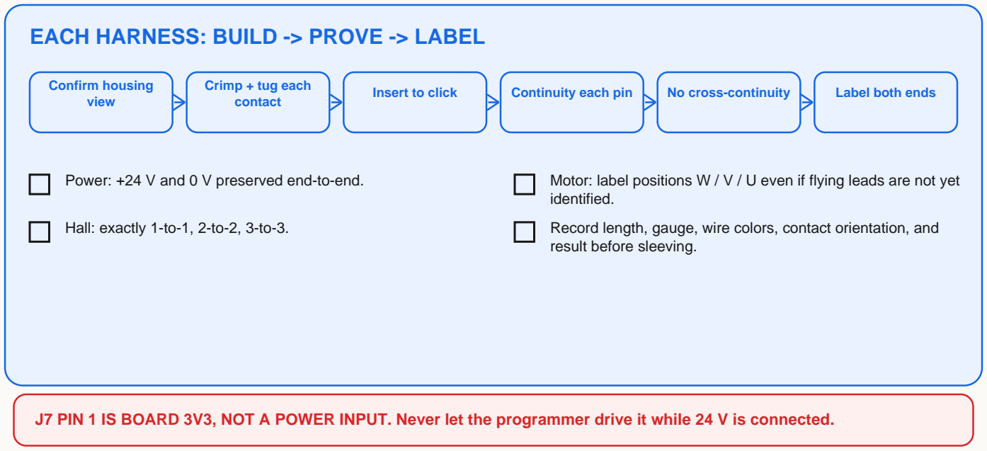
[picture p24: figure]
EACH HARNESS: BUILD -> PROVE -> LABEL; Confirm housing view; Crimp + tug each; contact; Insert to click; Continuity each pin; No cross-continuity; Label both ends; identified.; result before sleeving.

Power: +24 V and 0 V preserved end-to-end. | Motor: label positions W / V / U even if flying leads are not yet
Hall: exactly 1-to-1, 2-to-2, 3-to-3. | Record length, gauge, wire colors, contact orientation, and

J7 PIN 1 IS BOARD 3V3, NOT A POWER INPUT. Never let the programmer drive it while 24 V is connected.

STOP / HANDOFF | Every harness is labeled, pull-tested, and signed off for pin continuity and no cross-continuity.
SOURCE: docs/electrical.md, SCH-07 connectors; testing/test-matrix.csv | TESTS: TACH-06 PAGE 4

# 1D PCB-01 First Power, No Motor

## WIRE THIS FIRST; PLACE PROBES BEFORE POWER

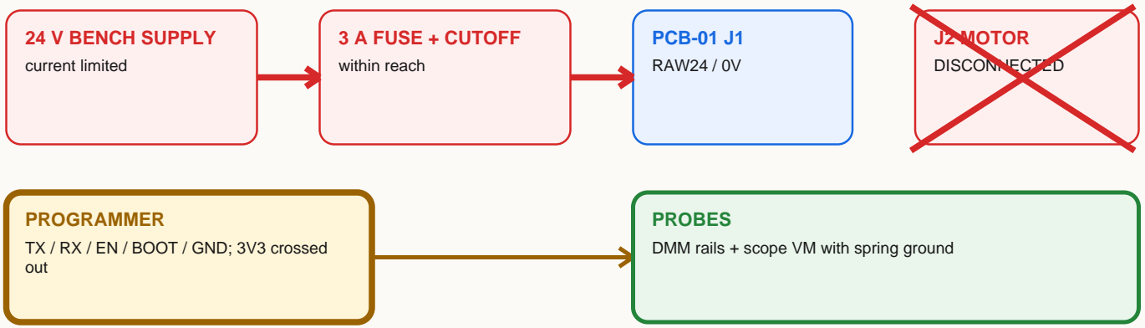
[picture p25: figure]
24 V BENCH SUPPLY; current limited; 3 A FUSE + CUTOFF; within reach; PCB-01 J1; RAW24 / 0V; J2 MOTOR; DISCONNECTED; PROGRAMMER; TX / RX / EN / BOOT / GND; 3V3 crossed out; PROBES; DMM rails + scope VM with spring ground

## NUMBERED TEST FLOW

### 1 RAILS

Brief power: 24 V, 3.3 V, AVDD, DVDD, DRVOFF; record current and heat.

### 2 HARDWARE CUTS

Force PGOOD, WDO, manual clear, OVERSPEED_N low one at a time -> DRVOFF rises without ESP help.

### 3 WATCHDOG

Static WDI: timeout 1.44-1.76 s, WDO pulse about 200 ms. 2 Hz falling edges prevent timeout.

### 4 STARTUP

Cold + slow-ramp power-up 20 times: U6 /PRE releases only after TACH_PGOOD_N.

### 5 RECOVERY

Remove/restore 24 V: disabled >=10 s; requires new command plus explicit arm.

### 6 TACH

Bridge disabled. Inject 0-3.3 V, 1-3% duty, settle >=30 s: reset ~3.00 Hz, trip ~3.33 Hz.

PASS LIMITS: VM <=35 V target; 40 V rejects. Persistent tach lock clears only on a genuine low-voltage power cycle. Any automatic re-arm blocks release.

STOP / HANDOFF | All listed board/safety tests have recorded passes. Do not connect the motor after any failure.
SOURCE: testing/test-matrix.csv; docs/electrical.md, safety and tach | TESTS: PCB-01, PCB-03/03B/03D, PCB-04, TACH-01 PAGE 5

# 3A Stationary Stack Dry-Fit

## EXPLODED SIDE VIEW - NON-POWERED

MP-100 -> ST-100
3 x M6 x 16 flat-head from plate ceiling face; heads flush or below.

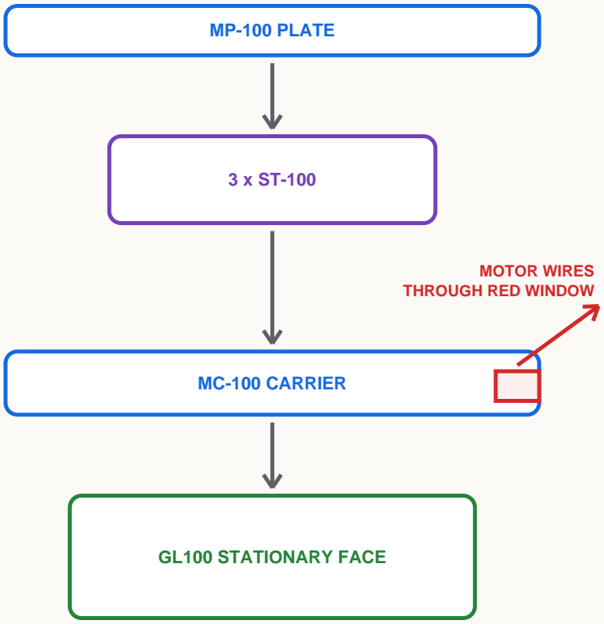
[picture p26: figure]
MP-100 PLATE; MC-100 CARRIER; GL100 STATIONARY FACE; MOTOR WIRES THROUGH RED WINDOW

ST-100 -> MC-100
3 x M6 x 20 A4-80 + Nord-Lock pairs. Hand-start, square seating.

MC-100 -> GL100
4 x M4 x 12 A4-80 into the 60 mm stationary pattern. The 50 mm face rotates.

THREAD DEPTH
Target about 5.5 mm engagement; 6.0 mm motor-thread maximum. A bottoming screw is felt at hand torque: stop and correct.

## RELEASE CHECK

All fasteners hand-start; no rocking or forced alignment. | Motor wire is unpinched and clear of sharp edges.
Owner-selected torque applied consistently; witness marks present. | Threadlocker only where specified; no screw bottoms.
Stationary 60 mm and rotating 50 mm faces confirmed. | Stack remains non-powered until later gates pass.
STOP / HANDOFF | Dry stack sits square without force, rocking, wire pinch, or bottoming screws.

SOURCE: docs/parts.md, GL100/ST-100/MC-100; bom/bom.csv PAGE 6

# 3B Rotor + Tach Inserts

B

HUB TO MOTOR
4 x M4 x 10 A4 flat-head from underside into 50 mm rotating pattern; heads 0.1-0.2 mm subflush. Pilot enters bore by hand only.

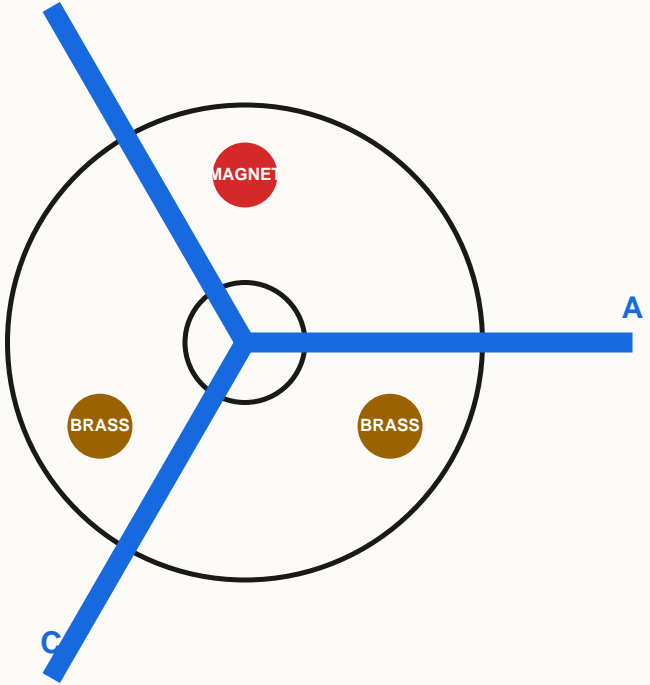
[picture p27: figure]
MAGNET; BRASS

EACH BLADE
BP-100 v3 locating pins + captured M5 nuts; 4 x M5 x 22 per blade. Torque consistently and witness-mark.

THREE INSERT STATIONS
Epoxy retains one magnet + two brass slugs. Match complete insert-plus-epoxy station masses within 0.01 g after cure.

## MASS + FINAL RECORD

MAGNET ______ g BRASS B ______ g BRASS C ______ g MAX SPREAD ______ g

Pilot hand-fit; all four hub heads subflush. | All three blade stations have four correct bolts and captured nuts.
Epoxy fully cured; inserts cannot move. | Hand-rotate several revolutions: no rub, click, or changing clearance.
Critical fasteners torqued and witness-marked. | Photograph rotor before balance measurements.

Do not use cad/BP-100.step for current fit; it is stale v2 geometry.

STOP / HANDOFF Complete rotor turns freely with correct retention; continue to 5A before powered motion.

SOURCE: docs/parts.md, RH-100/tach inserts; docs/blade-v2.md PAGE 7

# 3C Hall Gap + Electronics Bracket

## SECTION THROUGH MAGNET AND SENSOR

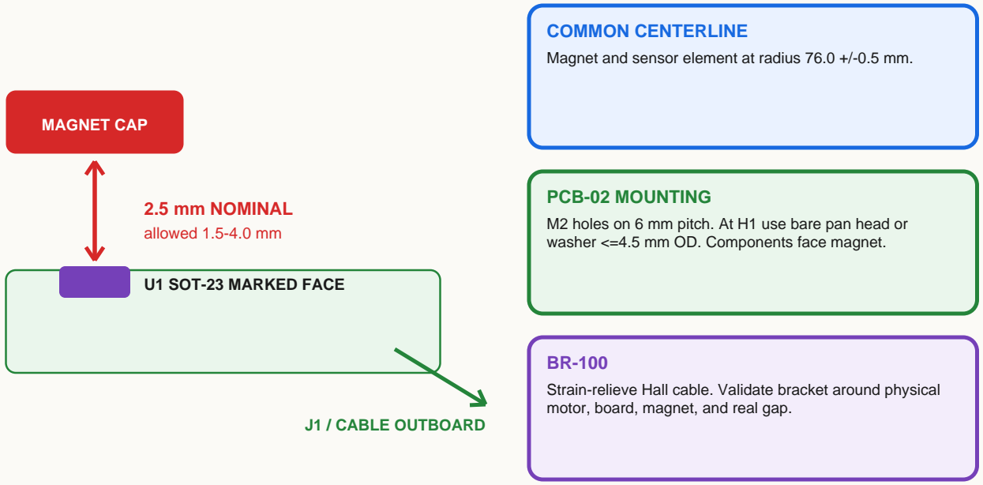
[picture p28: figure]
MAGNET CAP; U1 SOT-23 MARKED FACE; 2.5 mm NOMINAL allowed 1.5-4.0 mm; J1 / CABLE OUTBOARD; COMMON CENTERLINE; PCB-02 MOUNTING; motor, board, magnet, and real gap.

Magnet and sensor element at radius 76.0 +/-0.5 mm.

M2 holes on 6 mm pitch. At H1 use bare pan head or washer <=4.5 mm OD. Components face magnet.

Strain-relieve Hall cable. Validate bracket around physical

## PCB-01 BRACKET ENVELOPE

V1: 110 x 80 x 25 mm
V2: 120 x 90 x 30 mm SERVICE ENVELOPE

Four 6-8 mm M3 standoffs. Keep isolated mounting holes clear of circuit ground. Independent PCB retention and cable clamps. Preserve connector and cable-bend keepouts.

## HAND-ROTATION RELEASE

One clean pulse/revolution with magnet. | No false pulse with magnet removed.
All cables and connector bodies clear rotor. | Gap remains in range through full hand rotation.
STOP / HANDOFF | Hall pulse is clean; retained PCB and clamped cables clear all moving parts.
SOURCE: docs/electrical.md, Hall daughterboard; docs/parts.md, BR-100/EB-100 | TESTS: TACH-03 PAGE 8

# 4A Flash + One Persistent CLI Session

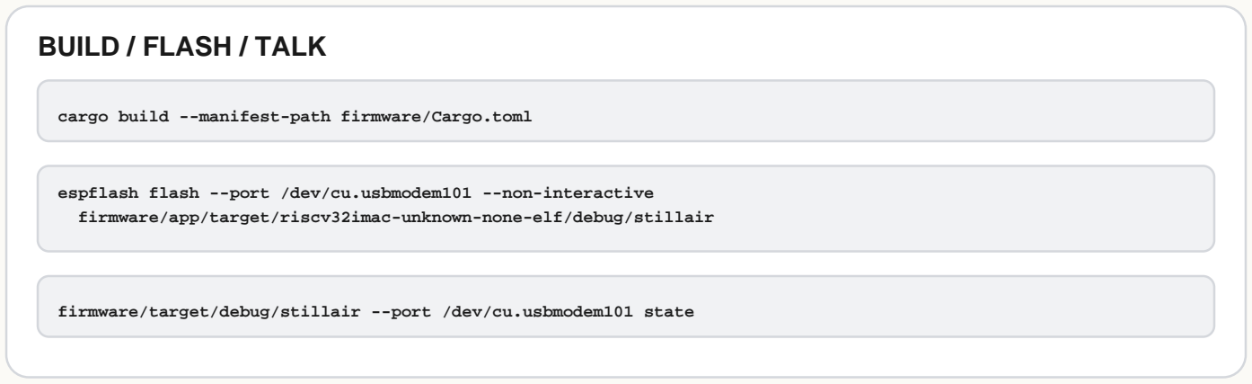
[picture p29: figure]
BUILD / FLASH / TALK; cargo build --manifest-path firmware/Cargo.toml; espflash flash --port /dev/cu.usbmodem101 --non-interactive firmware/app/target/riscv32imac-unknown-none-elf/debug/stillair; firmware/target/debug/stillair --port /dev/cu.usbmodem101 state

## BARE DEV-BOARD INPUT JUMPERS

GPIO22 -> 3V3
PGOOD good

GPIO21 -> 3V3
nFAULT idle high

GPIO14 -> GND
ALARM idle low
config stage | Starting | 15 s, no FG | NoRotation fault

EXPECTED ON A BARE BOARD; IT DOES NOT GENERATE FG EDGES

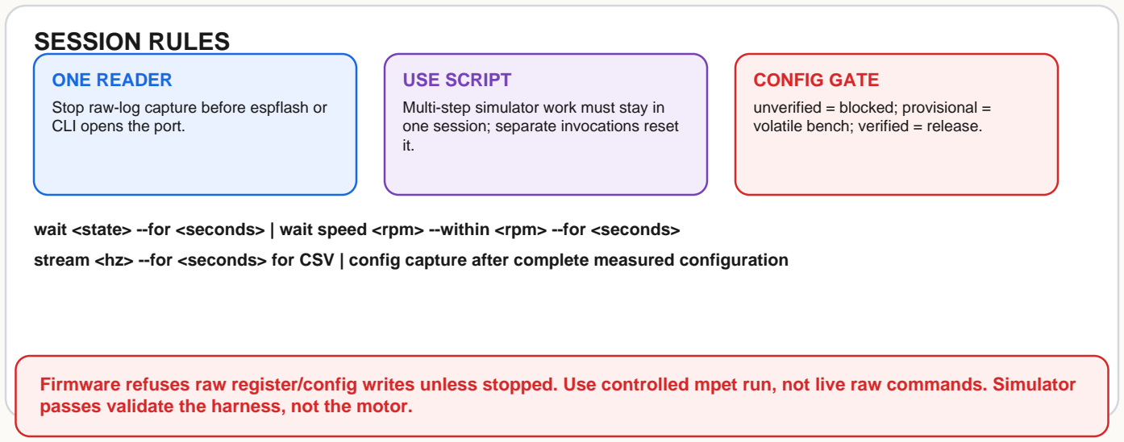
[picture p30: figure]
SESSION RULES; ONE READER; Stop raw-log capture before espflash or CLI opens the port.; USE SCRIPT; Multi-step simulator work must stay in one session; separate invocations reset it.; CONFIG GATE; unverified = blocked; provisional = volatile bench; verified = release.

wait <state> --for <seconds> | wait speed <rpm> --within <rpm> --for <seconds>
stream <hz> --for <seconds> for CSV | config capture after complete measured configuration

Firmware refuses raw register/config writes unless stopped. Use controlled mpet run, not live raw commands. Simulator passes validate the harness, not the motor.

STOP / HANDOFF Firmware flashes; one persistent CLI session communicates and preserves scripted state.

SOURCE: AGENTS.md, Driving the fan; firmware/cli/src/main.rs PAGE 9

4B Unloaded First Spin | VOLATILE BENCH IMAGE
NO BLADES | Motor secured; reachable power cutoff; board and Hall tests passed

### 1 POWER CYCLE

M

## 19.4 V

supply: 19.4 V / 2 A limit U-V: __________________
V-W: __________________
W-U: __________________

### 2 CONFIG STAGE

M

## CLI

expect: provisional
U-V: __________________
V-W: __________________
W-U: __________________

### 3 OBSERVED RUN

M

35

watch: smooth rotation
U-V: __________________
V-W: __________________
W-U: __________________

Double-align may make one or two small positioning ticks before smooth rotation.

## GREEN LANE - DO NOW

Power at 19.4 V with a 2 A supply limit; confirm normal idle draw. | Run config stage after each motor-power cycle; require provisional.
Issue a fresh run only after staging. | Use script 03 at 35 RPM; watch continuously and keep the cutoff reachable.

## LOADED-STAGE HANDOFF

No unloaded MPET; script 02 requires the representative loaded
rotor.

The provisional image is for this unloaded first-spin test only.

Never config apply the provisional image; it is volatile by design. | After final apply and power cycle require config check: verified.

Factory-unverified is blocked: a normal run would invoke implicit MPET with zero gains. Stage first. VM <=35 V target; 40 V rejects.

STOP / HANDOFF | 35 RPM starts, turns smoothly, reports FG, and stops cleanly. Loaded tuning remains separate.
SOURCE: docs/controls.md, measured-data gate; docs/electrical.md | TESTS: DRV-01, PCB-02, CTL-08/09/10 PAGE 10

# 5A Rotor Balance + Runout Record

A

B

DIAL INDICATOR AT RH-100 OD C

HUB RUNOUT
<=0.10 mm TIR

BLADE TIP HEIGHT
all three in one indexed setup; spread <=0.5 mm

FIRST MOMENT
each blade; spread <=0.5%

## A / B / C MEASUREMENT TABLE

STATION | MASS (g) | FIRST MOMENT | TIP (mm) | CORRECTION

A

B

C

## METHOD CHECK

0.01 mm indicator + 0.01 g calibrated scale. | First powered check starts low; stop for wobble, vibration, rubbing, or unusual sound.
Correct only by documented slug method; remeasure. | Hand-clearance pass and witness-mark photo saved.
STOP / HANDOFF | MEC-05 passes numerically; do not advance a rotor that only looks balanced.
SOURCE: testing/test-matrix.csv; docs/parts.md, RH-100 | TESTS: MEC-05 PAGE 11

# 5B Workshop Rotor Proof

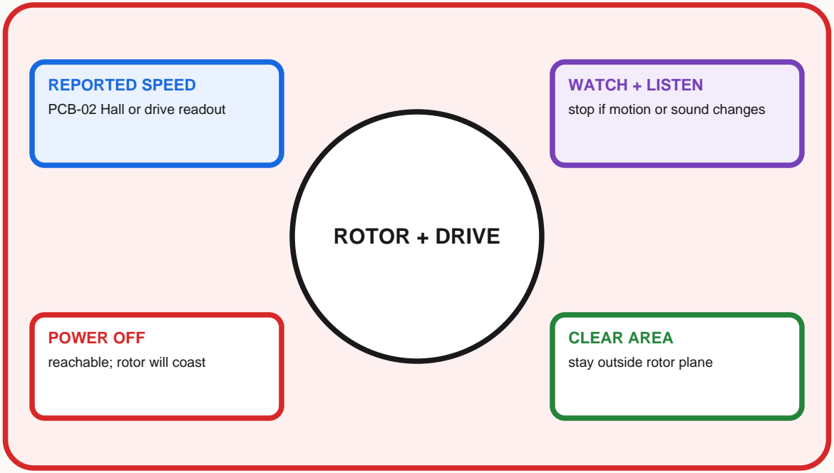
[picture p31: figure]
ROTOR + DRIVE; REPORTED SPEED; PCB-02 Hall or drive readout; WATCH + LISTEN; stop if motion or sound changes; POWER OFF; reachable; rotor will coast; CLEAR AREA; stay outside rotor plane

GL100 PHASES DISCONNECTED FROM PCB-01 | NO SAFETY BYPASS
PCB-02 MAY REPORT HALL SPEED; ANALOG TRIP MAY LATCH BUT WILL NOT STOP THE EXTERNAL DRIVE
START LOW | 216 RPM | 2 min CW | STOP + INSPECT | 2 min CCW | STOP + INSPECT

## 270 RPM = CALCULATION ONLY x NEVER DYNAMICALLY TEST

## BEFORE, DURING, AND RECORD

Setup secured; rotor plane and nearby area clear. | Speed source responds and is recorded.
Start low; advance only while smooth and quiet. | Watch continuously; cutoff remains reachable.
Balance, runout, clearance, witness marks recorded. | Inspect after each direction; stop on any change.

Speed source: ____________________________ Setup: __________________________________________

CW actual: ______ RPM result: __________ CCW actual: ______ RPM result: __________

Notes: __________________________________________________________________________________ Date / initials: __________________________________

STOP / HANDOFF | Both directions pass with no abnormal motion, sound, contact, loosening, or damage.
SOURCE: testing/test-matrix.csv; docs/parts.md, design loads | TESTS: MEC-03, MEC-07 PAGE 12

# 5C Loaded Commissioning Script Card HARDWARE VALUES PENDING

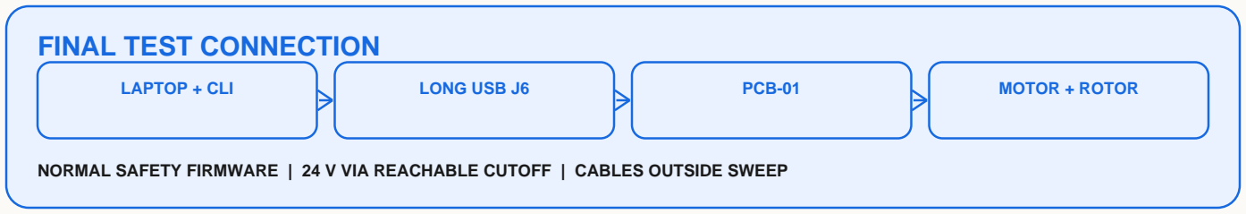
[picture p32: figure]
FINAL TEST CONNECTION; LAPTOP + CLI; LONG USB J6; PCB-01; MOTOR + ROTOR

NORMAL SAFETY FIRMWARE | 24 V VIA REACHABLE CUTOFF | CABLES OUTSIDE SWEEP

## CONTROLLED MPET + GOLDEN IMAGE

Run scripts/02-mpet-and-capture.txt only with the representative loaded rotor.

Review MTR_PARAMS, CURRENT_PI, and SPEED_PI against independent R / L / BEMF.
Put only reviewed D-generation values into the golden IMAGE. | While stopped, config apply performs one commit, waits 750 ms, polls self-clear, then verifies readback.
Power-cycle after apply; config check must report verified. | If MPET faults or times out, firmware aborts it and revokes drive permission.

MPET result / image revision: _________________________________________________________________

## RUN THE NUMBERED FILES

02 | scripts/02-mpet-and-capture.txt | loaded MPET + config capture
04 | scripts/04-loaded-speed-ladder.txt | 35 / 60 / 90 / 120 / 150 / 170 RPM ladder
05 | scripts/05-direction-check.txt | low-speed direction check through verified stop
06 | scripts/06-observed-run.txt | 30-minute continuously observed run

## WATCHED STOP RULES

| Keep the ordinary plug/cutoff reachable and watch continuously. | Stop for visible wobble, increasing vibration, rubbing, or unusual sound.
| Use reported FG diagnostics and your own observation; no external tachometer is required. | No permissive firmware or safety bypass. A stopped run may be repeated after inspection.
STOP / HANDOFF | Loaded MPET, verified config, speed ladder, direction check, and observed run have recorded results.
SOURCE: firmware/scripts/README.md; docs/controls.md, commissioning | TESTS: CTL-13/14; DRV-02/03/05/07/09 PAGE 13

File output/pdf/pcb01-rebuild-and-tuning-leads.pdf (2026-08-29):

1A PCB-01 Population Map | FIELD GUIDE

TOP / COMPONENT SIDE - KiCad target appearance


SOLDER ORDER: U8 -> C34 -> J1/J2 -> C1/C2 -> INSPECT -> F1 LAST 1 + 2 C1 / C2
EEU-FR1H471, 470 uF 50 V. Positive lead to board +; negative stripe to pin 2 / PGND. Seat square without crushing bung.

### 3 F1 - INSTALL LAST

Low-profile tinned copper link across the 1206 pads. Near-zero ohms after soldering. External wall-side 3 A fuse remains mandatory.

4 + 5 CONNECTORS
J1 43045-0200; J2 43650-0300. Larger chisel tip. Tack one electrical pin, square and fully seat housing, then finish. Locating pegs are not soldered.

### 6 U8 / 7 C34

U8 LM2907M/NOPB: notch/dimple to pin-1 marker, tack pin 1 then diagonal pin 8, flux and drag-solder. C34 C1206C104K3GACTU: 100 nF C0G 25 V +/-10%, spanning the smaller 0603 site, not shorting it.

PCB-01: USE THE IRON, NOT BROAD HOT AIR. Then clean and dry; inspect under the microscope; verify no hard short from RAW24, VM24, 3V3, or 12V_TACH to ground; photograph the board.

SOURCE: pcb/pcb-01/pcb-01.kicad_pcb; bom/bom.csv; docs/electrical.md, SCH-06 PAGE 1

1B Removable Tuning Leads | FIELD GUIDE

INSTALL ON THE BENCH BEFORE THE BOARD GOES OVERHEAD

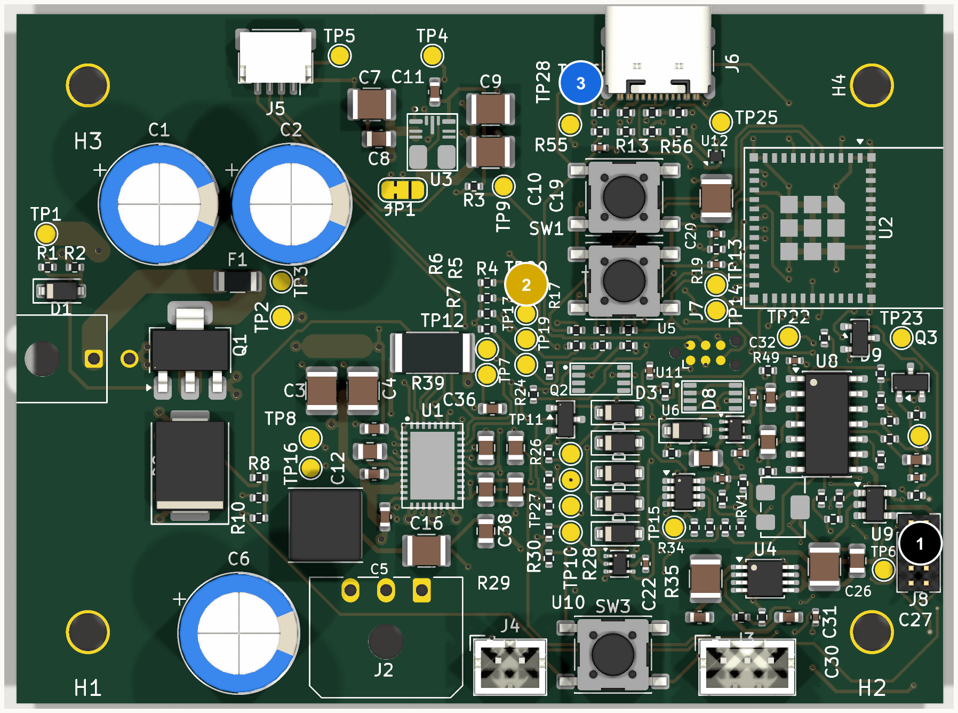
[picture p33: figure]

1 J8.9 SOX - BLACK | 2 TP20 FG - YELLOW | 3 TP26 AGND - BLUE

FIXED TUNING SETUP - DO NOT MOVE THE SCOPE
Physical leads: J8.9 SOX black, TP20 FG yellow, TP26 AGND blue. OWON CH1 uses black, CH2 uses yellow, and both common channel grounds use blue. Keep this hookup unchanged through unloaded and loaded tuning. Firmware already records SPEED, NFAULT, and DRVOFF.

VM24: ONE-TIME BEFORE TUNING
If the required bus capture is still open, complete it before fixing the OWON to these leads: x10 tip directly on TP2, spring ground on TP3. Do not substitute VM24 into CH2 during tuning.

FIT, INSPECT, REMOVE AFTER FINAL TUNING
All sources removed and bulk capacitors discharged. Solder once, route insulated wire flat, add Kapton strain relief away from each joint, inspect under magnification, then continuity-check every lead to its named net and for adjacent-pad shorts. Cap every free end before power. TP4 is also usable AGND; never wire motor phases, switch nodes, or USB data pads. Remove the pigtails after the complete exposed and housed tuning campaign, then clean and inspect.

OWON CHANNEL GROUNDS ARE COMMON. Never put one ground on AGND and the other on PGND in the same setup.

SOURCE: docs/probing.md; docs/observability.md; pcb/pcb-01/probe-map.json PAGE 2

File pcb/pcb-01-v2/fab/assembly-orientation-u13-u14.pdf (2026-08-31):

# PCB-01 V2 U13/U14 placement orientation

Component-side (top) view. Red pad is pin 1. J4 and board north are above both devices.

88 x 64 mm board context

J4 / NORTH
U13 U14

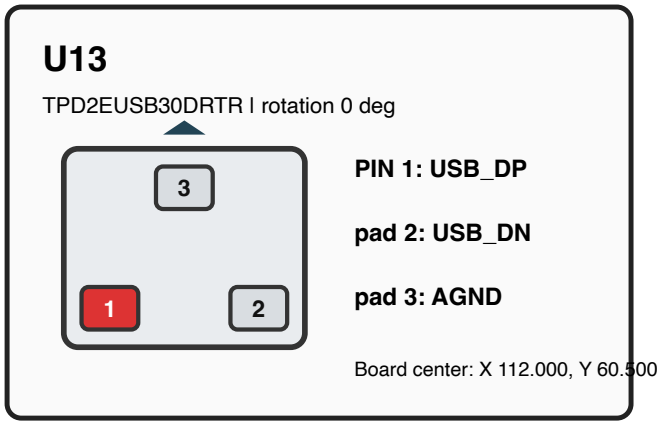
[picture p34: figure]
TPD2EUSB30DRTR | rotation 0 deg; PIN 1: USB_DP; pad 2: USB_DN; pad 3: AGND; Board center: X 112.000, Y 60.500
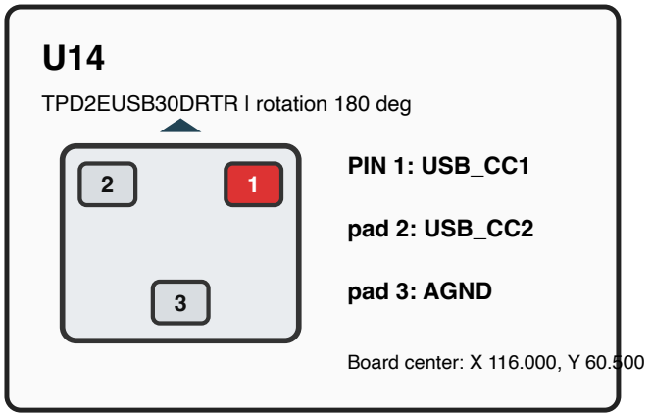
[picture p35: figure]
TPD2EUSB30DRTR | rotation 180 deg; PIN 1: USB_CC1; pad 2: USB_CC2; pad 3: AGND; Board center: X 116.000, Y 60.500

Approve JLC placement only when both red pin-1 pads and all channel nets match this top-view callout.

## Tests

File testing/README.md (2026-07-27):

# Testing

[`test-matrix.csv`](test-matrix.csv) is the commissioning matrix: every release test with its
method, acceptance limit, and blank Result/Owner/Date sign-off fields. Fill in results as
tests are run; limits are the minimum release basis and can be tightened once measured data
exists. Context for the phases lives in [../docs/build.md](../docs/build.md).

Prefixes: `PCB-` board bring-up, `TACH-` independent overspeed, `DRV-` motor drive, `CTL-`
supervisor/control, `MEC-` mechanical/rotor, `INS-` installation.

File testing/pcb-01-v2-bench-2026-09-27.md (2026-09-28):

# PCB-01 V2 bench flash and interim configuration

Michael reported the V2 board assembled on 2026-09-27. The motor remained disconnected.
The requested scope was a powered bench/USB check, firmware flash, and persistent settings for
installation and interim use. Michael explicitly deferred additional intermediate motor tests
until a problem is reported or final tuning is requested.

## Final handoff

**Ready for installation and interim use with the normal provisional firmware.** Apple Home
pairing succeeded, both Home fabrics survived a board-only reset, and Michael's Home controls
reached the board after that reset. Final telemetry is `idle_off`, `fault=null`, `on=false`,
`cmd_mrpm=0`, `duty=0`, `config=verified`. The saved loaded MCF image is unchanged.
Keep UniFi multicast enhancement enabled on SyNet-2G; the group-key interval is back to
3,600 seconds. The final validation and exact installed ELF hash are recorded below.

## Initial bench result

- Owner-reported supply: 19.71 V, 0.30 A current limit, stable 0.026 A before flashing.
- V2 probe map: 31 test points and four connectors verified against the committed board;
  component-side assembly render inspected.
- USB at `/dev/cu.usbmodem2101`: ESP32-C6 revision v0.2, 40 MHz crystal, 8 MB flash;
  MAC `20:6e:f1:12:a5:b0`. Native ROM communication, flashing, reset, and runtime CLI succeeded.
- Firmware source: `af12fec55430b4af7704dd89636bdd102a0c4158`, unchanged release build.
  ELF SHA-256: `91b2b829389e7ef1ebbb873db16305ae23cc8b445f3e4f37b118e127eb789487`.
  Host tests: 41 CLI and 193 core passed. Release build passed using rustup's PATH shims.
- Initial factory image correctly produced `config_mismatch` at `MOTOR_STARTUP1` (`0x084`).
  Gate-driver and controller fault registers both read zero. The original configuration is
  retained in [factory-config.txt](pcb-01-v2-bench-2026-09-27/factory-config.txt).
- `config apply` saved the existing 2026-08-21 `LOADED_IMAGE`: 15 changed words, nine unchanged,
  commit acknowledged, complete readback `verified`. No `config stage` or tuning variant used.
- `fault clear` followed by the normal 10-second safe-boot hold reached `idle_off`, `fault=null`,
  `on=false`, commanded/measured speed zero, `config=verified`. Both fault registers remained zero.
  `VM_VOLTAGE` raw readback was `44171263`; no independent rail-voltage claim is made from this.
- Matter started, opened BLE commissioning, and found its persistent NVS partition at
  `0x9000..0xf000`. Apple Home initially failed; the later successful add and retained Home
  pairing are recorded below. Installation has not been reported.

Evidence: [flash](pcb-01-v2-bench-2026-09-27/flash.log),
[EEPROM apply](pcb-01-v2-bench-2026-09-27/config-apply.log), and
[final checks and all 24 register values](pcb-01-v2-bench-2026-09-27/final-check.log).

## Scope and continuation

The bench task passed within the scope above. Full V2 qualification is not claimed. No rail
probing, analog overspeed calibration, sensor calibration, dedicated cold power-cycle readback,
two-cable/two-orientation USB check, unpowered USB back-feed check, or interrupted-flash recovery
test was performed. Michael later exercised Home controls with the motor disconnected; those
commands and the resulting bench faults are recorded below. Existing V1 results remain
attributed to V1.

Apple Home pairing and the final unattended checks have succeeded. Michael's next step is
installation using the saved loaded configuration. Firmware always powers up off and requires
a fresh user command after safe boot. EEPROM settings and paired Matter credentials are
designed to persist across power loss; this session verified persistence across ESP resets,
not a dedicated full-board cold power-cycle. Final loaded tuning stays deferred by Michael's
instruction.

## Tooling observations

- The first serial open returned `Device or resource busy`; a subsequent open succeeded and no
  competing reader was found. No cause was established.
- `check_board_usb.py` reported no VID/PID device despite the immediately subsequent successful
  native ROM connection. Its I/O Registry result is unresolved and must not override actual
  successful device communication.
- The first flash wrote the image but failed its requested watchdog reset because ESP32-C6 does
  not support that espflash option. Repeating with `--before usb-reset --after hard-reset` verified
  the image and completed successfully. No manual button sequence was needed in this session.

## Apple Home pairing follow-up

Michael reached the uncertified-accessory confirmation, accepted it, and then received
`Pairing Failed`. The [raw serial excerpt](pcb-01-v2-bench-2026-09-27/pairing-failed.log)
shows successful attestation, CSR, trusted-root and NOC installation, followed by joining the
intended 2.4 GHz network and obtaining `10.10.1.21`. The initial signal was -63 dBm. The final
177-second fail-safe expired for tentative fabric 1; the expected `Got Commissioning Complete
Request` and `Commissioning complete, fabric and network settings persisted` messages never
appeared. Failure is in the operational-network handoff, not the uncertified-accessory warning.
The exact cause remains unresolved.

From the Mac at `10.10.1.90`, Bonjour resolved the board's commissionable service to
`206EF112A5B00000.local.:5540`, IPv4 `10.10.1.21`, and IPv6
`fe80::226e:f1ff:fe12:a5b0%en0`. Three IPv4 and three IPv6 echo probes received no replies;
IPv4 ARP remained incomplete. These are observations, not proof of an AP-isolation fault or
firmware defect. The first operational-service browse happened after rollback, so absence of a
board operational service then cannot establish its availability during the failed attempt.
Packet capture was unavailable because the process lacked BPF-device permission.

A new raw serial capture and operational Bonjour browse were started for a requested retry.
That retry supplied **`SyNet`**, unlike the first attempt's **`SyNet-2G`**. The radio reported
`DisconnectedInfo { ssid: "SyNet", bssid: [0, 0, 0, 0, 0, 0], reason: NoAccessPointFound,
rssi: -128 }`, which the driver maps to `NoNetworkInterface`. `Wifi already connected,
disconnecting first` is normal retry handling, not evidence of a stale-state bug. The retry's
cause is therefore a network the C6 could not find; it does not explain the first attempt's
post-join timeout.

The ESP was reset through native USB, verified the saved MCF image at target `0x01`, and reopened
BLE commissioning. Michael kept the iPhone on **SyNet-2G** for subsequent attempts. No EEPROM
or firmware changes were made during this initial diagnosis. Build comparisons follow below.

## Build-profile comparison

Michael confirmed that V1 paired on this network and asked whether changing from MINI to WROOM
needed different firmware. Both modules use ESP32-C6 and a 40 MHz crystal. V2's ALARM input is
already GPIO10, and espflash detects the N8 module's 8 MB flash. The module swap does not select
a different CPU target or Matter implementation.

Comparison with the successful V1 revision `1633433` found no changes to `matter.rs`, app
`Cargo.toml`, app `Cargo.lock`, or executor priorities/heap/Matter allocation. The new low-rate
RSSI sampler is the only added periodic radio API call; no evidence currently implicates it.
The V1 bench workflow used `cargo build`, whereas the initial V2 flash in this session used
`cargo build --release`. The dev profile optimizes esp-radio at level 3; release uses level `s`.
Both levels are supported by the pinned esp-radio build script, so this is a diagnostic comparison,
not an established cause.

The unchanged-source **dev-profile** build was flashed successfully at
2026-09-28 01:28 UTC. ELF SHA-256:
`6892d5de13f979f10bfe9f605e4f810016b212364014681dd354f7444b4c68a6`.
The [dev flash receipt](pcb-01-v2-bench-2026-09-27/flash-dev.log) records the same C6 revision v0.2
and 8 MB flash. No NVS erase or MCF configuration write was performed. Boot re-verified the saved
image; the expected MCF watchdog fault after the flash pause cleared with `fault clear`, then the
normal safe-boot hold reached `idle_off` with clean MCF status. A fresh SyNet-2G pairing attempt
failed again. Michael moved close to the AP and confirmed the iPhone was on 2.4 GHz. The log
confirmed SyNet-2G, excellent -48 dBm RSSI, DHCP at `10.10.1.21`, and the same fail-safe timeout
without commissioning completion. The profile change did not fix pairing.
See the [dev pairing capture](pcb-01-v2-bench-2026-09-27/pairing-dev.log).

## Sequential commissioning experiment

The firmware briefly used the pinned stack's supported `run()` path instead of `run_coex()`, releasing
BLE before Wi-Fi starts. The arena grew from 20,000 to 32,000 bytes for the larger futures.
This tests radio coexistence as a cause of the handoff timeout; it is not an established fix.
Upstream notes Alexa incompatibility for this mode; the requested controller is Apple Home.

The first sequential build exposed a separate bug in `wifi_diag`: its five-second initial RSSI
sample called `esp_wifi_sta_get_rssi` before Wi-Fi initialization and panicked at
`current_task_is_wifi_task`, with `Load access fault (5)`, `mtval=0x000000a4`.
The sampler now mirrors the pinned safe `WifiController::rssi()` wrapper: call
`esp_wifi_get_mode` first and only read RSSI after a successful STA/APSTA mode result.
The mode query explicitly supports an uninitialized driver. No await separates the two calls,
so Matter cannot drop its controller between them on the shared thread executor. This fixes the
observed diagnostic-build boot failure; it does not establish the earlier pairing timeout's cause.

The corrected dev image was flashed at 2026-09-28 01:46:59 UTC, SHA-256
`60317c6dedb68208f3d4473eaca31c45c664008d054e7b212b2714cd996d054e`.
Formatting, clippy with warnings denied in both workspaces, all 234 host tests, and the app build
passed. Focused source review confirmed the API and FFI signatures. The corrected image booted
past the previous crash, advertised BLE commissioning, and showed 24,164 bytes allocated in the
32,000-byte arena during BLE-only startup. Nine unavailable RSSI polls completed without a crash;
`fault clear` cleared the post-flash MCF watchdog fault and the board reached `idle_off`.
No NVS erase or MCF image change was performed.

Michael's retry failed immediately. The log showed successful AddNOC, followed by
`Error invoking command: InvalidAction`, then the phone disconnected before any Wi-Fi scan or
join. The pinned sequential `WirelessNetCtl::Commissioning::scan()` explicitly returns
`InvalidAction`; earlier Apple attempts scanned immediately after AddNOC. This strongly indicates
that Apple's ScanNetworks request hit that stub, but the failing command ID was not logged.
The experiment did not solve pairing. Concurrent mode and the 20,000-byte arena were restored,
retaining the confirmed RSSI initialization fix.
See the [sequential pairing capture](pcb-01-v2-bench-2026-09-27/pairing-sequential.log).

## Transport diagnosis in progress

The optional `matter-diagnostics` build feature enables only `rs_matter::transport` DEBUG headers
on USB, retaining INFO elsewhere and disabling TRACE. The resolved dependency feature tree was
checked: `debug-tlv-payload` is absent. Default and diagnostic builds both pass clippy with
warnings denied and build successfully. Review confirmed logger filtering and packet-header-only
output. The new capture should distinguish missing operational packets from an incomplete CASE
exchange instead of inferring either from INFO-only logs.

At Michael's request, both the product name and mDNS commissioning name changed to `Stillair`.
These static details do not come from the persisted node label. The pinned stack hardcodes its
BLE local name to `BT`, so Apple Home's initial discovery tile may still show a generic type.
The concurrent diagnostic image with these names was flashed at 2026-09-28 01:53:46 UTC;
ELF SHA-256 `5916be19ebb1b687c40d914f3aa4455dc116e8b0ebdc4766d464e0b2adf41b4a`.
It booted and, after clearing the post-flash watchdog fault, returned to `idle_off`, `fault=null`,
`config=verified`. Michael's retry failed with Home's "Connect to a 2.4 GHz wifi and try again"
message, despite confirmed association to SyNet-2G. The packet capture shows BLE provisioning
and a successful connect response, but no received operational Matter packet over UDP. The
serial dropped-line count stayed at 23 before and after provisioning, so no additional dropped
output explains the missing handshake. The 177-second fail-safe expired and removed fabric 1.

During that attempt, operational service `00A24DE50CF9BB3D-00000000489422F0` resolved to the
board's `206EF112A5B00000.local.:5540`. Commissionable service `A9BFEC3B54CEB19B` resolved to the
same host with **`DN=Stillair`**, confirming the requested advertisement name on the LAN. Both
IPv4 `10.10.1.21` and IPv6 `fe80::226e:f1ff:fe12:a5b0%en0` resolved. Two IPv4 and two IPv6 pings
failed; IPv4 ARP remained incomplete. A fresh legacy-unicast mDNS query also received no reply
within four seconds. Discovery visibility alone does not prove unicast reachability.

Source inspection found that normal GATT disconnection resumes advertising without dropping the
Embassy network runner; ARP/NDP processing is independent of Matter's UDP/BTP receive selection.
Neither AP isolation nor a radio RX/TX failure is established. Michael confirmed UniFi and
authorized checking its configuration via an MCP or CLI. Controller access is the next diagnostic
step before requesting another pairing attempt.

Evidence: [transport capture](pcb-01-v2-bench-2026-09-27/pairing-transport.log),
[transport diagnostic flash](pcb-01-v2-bench-2026-09-27/flash-transport-stillair.log), and
[operational discovery](pcb-01-v2-bench-2026-09-27/mdns-operational.log).

## UniFi inspection and radio identity

`unifly` 0.10.0 was installed locally and connected to the UCK G2 Plus at `https://10.10.1.200`
(Network 10.6.106). Profile `home` uses the `default` site; its API key is in macOS Keychain
under service `unifly`, account `home/api-key`, not in this repository. The router at `10.10.1.1`
is separate. No Executor MCP connection was added because the CLI supplies the needed reads.

UniFi confirmed this station on SyNet-2G, authorized and not blocked, with power saving off.
The serving AP is U7 Pro `8c:30:66:6c:79:bc`, `10.10.1.95`, firmware 8.7.11.19419, channel 6,
20 MHz. Raw station counters after about eleven minutes showed 56 received packets / 40,856
received bytes at the AP, but zero transmitted packets, bytes, or attempts for this station.
These counters warrant investigation; they do not alone prove an AP defect.

The WLAN is WPA2/CCMP, 2.4 GHz only; client isolation, guest mode, MAC filtering, multicast
filtering, proxy ARP, fast roaming, PMF, U-APSD, and MLO are off. IoT optimization is on.
The Default LAN reports isolation off. Its IPv6 setting is off, which is not by itself an
explanation for failure of link-local Matter traffic or IPv4 ARP.

A board-only reconnect was attempted: the CLI's Integration API `RECONNECT` action failed
with `Invalid $.action value`; the supported legacy `kick-sta` command returned `rc=ok`.
The board logged link-down and disappeared from connected clients. It did not automatically
rejoin after the failed commissioning had rolled back its network credentials. No SSID, AP,
firewall, VLAN, or other client configuration was changed.

An extended diagnostic image was flashed at 2026-09-28 02:11:15 UTC, SHA-256
`d03519a179876afc90ee227806bfc97ae61bee09bec82455a04cd03f90429cde`.
It adds mDNS query/reply metadata and a one-shot read of the vendor station MAC. At boot,
`esp_wifi_get_mac` returned success and `20:6e:f1:12:a5:b0`, matching both the eFuse-derived
address and the earlier network-interface log. PHY reported `Some(DataCheckFailed)`; that enum
describes saved calibration-data validity, not an RF health test. The pinned stack performs
full calibration when no saved data is supplied. Both feature/default builds and clippy passed;
focused review found no driver ownership changes or payload/key logging.

Michael's next retry failed. The board again joined SyNet-2G and acquired `10.10.1.21`, but
logged no mDNS replies or incoming Matter UDP. The 177-second fail-safe expired. The serial
dropped-line counter remained 15 before and after this attempt. Fresh directed mDNS queries
and Mac pings failed; ARP remained incomplete. In this association UniFi did count two outbound
AP packets, so the earlier zero-counter observation is not a universal absence of AP traffic.

Read-only SSH access to the AP was obtained using its existing controller-managed credentials,
held in process memory. A 20-second capture on `wifi0ap0` showed the Mac's query and ARP requests
from both Mac and AP on the correct WLAN, plus fresh IPv4/IPv6 mDNS advertisements transmitted
by Stillair. This confirms continuing board transmission, not merely cached discovery or a
queued log message. The AP bridge forwarding table places the board MAC on `wifi0ap0`.
Neither the Mac nor the AP received an ARP reply. A temporary board-only neighbor entry on
the AP bypassed ARP for four unicast pings; all four failed. The entry was removed immediately
afterward. Subsequent source review found that the app does not enable smoltcp 0.13.1's
`auto-icmp-echo-reply` feature, so these ping failures do **not** establish unicast receive
failure. ARP/NDP and a directed mDNS query remain the useful probes. AP station counters showed
no transmit failures, but that is not proof that the ESP delivered those frames to its IP stack.
No persistent AP/WLAN setting was changed.

An AP-originated UDP unicast query, with a temporary neighbor entry bypassing ARP, received an
immediate valid 128-byte mDNS A/AAAA response. The otherwise identical query sent to
`224.0.0.251` timed out. This proves the app's unicast path works and narrows the failure to
incoming group traffic. Temporary multicast and broadcast rate changes from 1 to 6 Mbps did
not help and were restored to 1 Mbps. The legacy `mcastenhance 2` command read back as 0 and
had no demonstrated effect; 0 was explicitly restored. No controller setting was changed.

## Autonomous group-traffic diagnosis

Michael authorized continuing with tools and firmware while away, without further phone/button
steps. A temporary Wi-Fi-only baseline used the same pinned ESP driver, DHCP, and IPv6 setup,
with BLE/Matter absent and automatic ICMP echo replies enabled. Credentials were supplied
privately through the compiler child environment; its source and credential-bearing build
outputs were kept in a mode-0700 task directory outside the repository until final cleanup.
It performs no motor,
GPIO, or persistent-storage initialization. The fan image was saved for restoration.

Initial Mac pings succeeded, but this did **not** prove group reception: a later AP capture
showed the Mac sending unicast ARP to a cached MAC, which the board answered, while broadcast
ARP from the AP went unanswered. IPv6 neighbor discovery also failed. The Wi-Fi-only baseline
therefore reproduced the original group-traffic failure without Bluetooth.

A second scratch baseline counted Ethernet destination classes before passing unmodified
frames to Embassy. After DHCP, it counted three unicast frames and zero broadcast ARP, IPv4
multicast, or IPv6 multicast frames. Fresh broadcast probes did not increase group counts.
Two existing SyNet-2G devices, an Espressif-based thermostat and a TP-Link plug, also failed
broadcast ARP while answering ordinary unicast pings. The same broadcast-ARP tool received
two replies from the wired router, validating the probe path.

One U7 Pro restart was initiated through UniFi at **2026-09-28 02:33:49 UTC**, with its settings
unchanged. The same running board image reconnected and immediately began receiving group
traffic. Its counters reached 4,413 broadcast ARP, 777 IPv4 multicast, and 1,061 IPv6 multicast
frames while unicast remained functional. Mac IPv6 ping passed 2/2. Fresh forced-broadcast ARP
from the AP then received 2/2 replies from each of the board, thermostat, and plug.

This is direct before/after evidence of failed group delivery on the AP/WLAN, restored by the
AP restart without a firmware change. The internal AP failure mechanism and recurrence risk
are unknown. The observed failure reproduced without Matter or Bluetooth, and the same C6
target worked after the restart. Home's 2.4 GHz message did not identify this failure accurately.

Evidence: [AP packet excerpt](pcb-01-v2-bench-2026-09-27/ap-reachability.txt) and
[Ethernet counters across the AP restart](pcb-01-v2-bench-2026-09-27/wifi-group-counters.log).
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

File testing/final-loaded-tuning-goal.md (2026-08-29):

# Final loaded tuning goal

Use the following objective verbatim when Michael asks to start final tuning. Persisting this text
does not activate or set a goal.

Execution details may adapt to the working hardware, firmware transport, and observability tools
available at launch. Preserve the objective's scope, safety boundaries, evidence standard, and
completion criteria; do not require an obsolete implementation detail when an equivalent verified
path is available.

Objective: Autonomously optimize the installed, fully loaded Stillair fan to the best performance physically achievable with the
current motor, controller, rotor, and released safety architecture, leaving no meaningful controller parameter, configuration,
diagnostic path, or measurable improvement unexplored. Begin with the exposed assembly and untouched loaded golden image. Use
synchronized fixed-position close-microphone audio, OWON SOX/electrical captures, Hall/FG, supervisor and MCF telemetry, Kasa
power, and camera evidence where motion or rotor position matters. Systematically diagnose and minimize reducible electrical/
commutation tones, intermittent chirps, rough alignment/open-loop/closed-loop handoff, speed error, instability, current
distortion, and avoidable power loss; iterate until additional safe changes produce no objective or repeatable subjective
improvement. Prove smooth reliable starts, stops, reversals, regulation and acoustics across the released 50–170 RPM loaded
range, both directions where required, persistence, fault behavior, repeatability, and endurance before freezing a new golden
configuration. Michael confirms the installed fan is clear and will continuously watch it with the immediate physical cutoff
available; Codex is preauthorized to autonomously operate the fan, issue speed/direction/stop commands, power-cycle through the
available control path, flash firmware, stage volatile MCF settings, run scripts, collect and analyze evidence, and use all in-
scope instruments and tools without pausing for routine permission, while never bypassing hardware protections, exceeding
released limits, or performing a physical intervention blindly. Keep the close microphone independently supported just outside
the future housing envelope and fixed for the complete comparison; skip a formal bed-position recording, using Michael’s final
listening judgment instead. After the exposed finalist is fully captured, guide only the unavoidable physical installation of
the already-decided motor damping panels and completed upper housing with interior damping, then re-run the fixed-mic acoustic
ladder and final mechanical/thermal qualification without changing the tune; resume controller tuning only if the completed
assembly exposes an objectionable controller-related sound. Finish only when no meaningful safe improvement remains, the best
configuration passes the full applicable release matrix, all findings and evidence are documented, review findings are resolved,
verification is green, and the completed work is committed and pushed.

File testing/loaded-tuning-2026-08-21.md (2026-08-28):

# Loaded tuning, 2026-08-21

The first ceiling-mounted powered work began with the retained unloaded image in volatile shadow,
with Michael continuously observing the clear room and holding the physical cutoff. Serial
telemetry and Kasa wall power were recorded; no camera was available. No loaded MPET was performed.

## Installed Hall and first motion

- The first hand-rotation trial proved the mounted Hall signal but exposed that the board was
  still running firmware from before the five-second Hall-estimate expiry fix. The current
  qualified binary was flashed while the controller remained in unverified SafeBoot.
- Two slow hand revolutions on current firmware produced clean edge-period estimates and the
  Hall speed returned to zero after the five-second quiet window. The bridge remained disabled.
- A scripted 35 RPM loaded start then acquired cleanly, settled at about 35.5 RPM on both FG
  and Hall, looked smooth by owner report, and stopped normally. Startup wall power peaked at
  4.43 W and the steady 35 RPM input was about 1.55 W.

## Apple Home sweep

- Matter commissioned successfully to `SyNet-2G` and the `Uno Condo` Apple Home. Fabric and
  network state persisted; the controller obtained `10.10.1.25` and Apple subscriptions opened.
- A later start commanded from Apple Home at 35--40 RPM rocked back and forth without acquiring.
  Raising the slider to exactly 10% commanded 47.27 RPM and acquired cleanly. This makes 35 RPM
  an unsuitable released loaded floor despite the earlier successful start; 50 RPM is the
  provisional floor with a small margin.
- Michael increased the slider gradually through the range. Motion remained solid by owner
  report, Hall and FG stayed in close agreement, no controller fault appeared, and 100% mapped
  to 170 RPM. Wall power peaked at only 5.03 W.
- Downward Matter targets reached the supervisor, but the 1.5 RPM/s ramp made the response look
  stuck after the fast manual sweep. Wall power fell from about 5.03 W to 3.69 W before Michael
  cut Kasa power. The cutoff registered cleanly. The next candidate uses the already-released
  upper commissioning rate of 3 RPM/s.

## Released candidate

- Released minimum: 50 RPM.
- Acceleration/deceleration: 3 RPM/s.
- Retain the qualified unloaded MCF values as the loaded candidate rather than introducing an
  unmeasured MPET result.
- Use the MCF digital-speed override for both provisional and verified operation. The physical
  1 kHz SPEED input did not produce motion after the image first became verified; digital control
  is the path exercised by every successful loaded run.

## Start, range, and endurance evidence

- The 50 RPM / 3 RPM/s candidate completed three consecutive cold-position starts before a fourth
  run reported `BusUnreachable`. After a power cycle it completed four more consecutive starts.
- The bus fault was a stale-reader timeout: the high-rate Matter/Wi-Fi work could starve the MCF
  status task on the shared thread executor. Moving MCF service to its own priority-2 interrupt
  executor, below the priority-3 safety loop and above network work, removed the failure. An
  approximately eight-minute hold remained physically healthy through a USB telemetry pause, and
  an independent ten-minute 50 RPM endurance run completed with no fault. FG stayed near
  49.5--50.3 RPM, Hall stayed centered near 50 RPM, and steady wall power was about 1.67--1.77 W.
- A fixed command ladder reached about 50, 100, and 170 RPM with Hall/FG agreement and no fault.
  The down-ramp command now changes at 3 RPM/s, but the loaded rotor's observed coast from 170 to
  about 106 RPM took over 50 seconds. Explicit Off remained clean.

## Golden image and final boot proof

- A complete 24-register loaded image was captured and committed once while stopped. EEPROM
  recomputed the read-only parity bit in several words, so the stored post-commit values, not the
  volatile pre-commit parity bits, are the golden comparison.
- The first capture also exposed an EEPROM-latched trap: live `DEVICE_CONFIG1.I2C_TARGET_ADDR`
  read as zero even though the part was responding at its factory address. That capture moved the
  part to reserved target `0x00` after reboot. Recovery now probes `0x00`, and the golden image
  explicitly stores target `0x01`; a second commit restored the normal address.
- A cold power cycle found the MCF at `0x01`, reported the stored configuration verified and fault
  status clean, restored both Matter fabrics, and returned to stopped operation without staging.
- In verified mode, `pct 1` then acquired the loaded rotor and held for three minutes at about
  51.1 RPM FG / 50.2 RPM Hall with no fault and about 1.7--1.8 W steady input. After a further full
  Kasa power cycle, the image and Apple Home state restored again; another 1% start and one-minute
  hold ended at 51.1 RPM FG / 50.4 RPM Hall and stopped cleanly to zero.

## Provisional-use boundary

This release establishes reliable starts and continuous operation at the 50 RPM floor, continuous
Apple Home control through 170 RPM, responsive command changes, independent Hall/FG agreement,
clean stopping, and persistence. Loaded MPET, randomized multi-voltage start matrices, fixed loaded
plateaus, acoustic assessment from bed, and long maximum-speed thermal endurance remain later
qualification work; they are not claims made by this commissioning result.

## Owner observations after provisional use

- The fan subsequently ran perfectly all night at the 1% setting (the 50 RPM released floor) by
  owner report. At that setting its motor/electrical noise was minimal and almost inaudible, so the
  provisional floor is already usable for sleep despite the remaining acoustic work.
- Higher settings have a consistent coil-whine/electrical tonal character. Treat this steady tone
  separately from the intermittent event during capture: compare its frequency, harmonics, and
  sidebands against PWM, commutation, electrical angle, SOX, speed, and load at matched RPM.
- The occasional sound is better described as a short chirp-like event than a generic squeak. Its
  source is not yet identified; preserve it as a symptom rather than assuming bearing lubrication.
  The next capture should test whether chirps are periodic with rotor angle, confined to startup or
  target changes, correlated with SOX/current distortion, or independent of drive state before any
  lubricant or mechanical intervention is chosen.
- Acceleration from rest is not subjectively smooth. The next session should capture the complete
  align/open-loop/handoff sequence and tune startup separately from steady-state acoustic changes.

## Synchronized loaded-tuning plan

The dedicated microphone has arrived and is usable; the OWON is expected roughly seven days later.
Because physical setup is easier to batch and the current golden image is already pleasant in use,
defer candidate tuning until the scope is present. A short microphone shakedown may verify format,
gain, mounting, and clipping, but it is not the formal reference and changes no motor setting.

Source tuning uses the exposed assembly. The decided 2 mm butyl/film automotive damping panels on
the motor and inside the stationary upper housing are a later passive improvement, not part of
finding the controller tune. Install them only after the exposed finalist has been captured, without
changing that finalist, then measure the completed assembly as a separate final-system validation.

### Launch and autonomous authority

Michael has preauthorized the upcoming run. Saying `next`, `begin the loaded tune`, or equivalent
is the launch signal and confirms that the installed fan is clear, he is continuously watching it,
and the immediate physical cutoff is available. After the one-time physical hookup is validated,
Codex may autonomously issue speed, direction, and stop commands; power cycle through the available
control path; flash firmware; stage and restore volatile MCF configurations; run acquisition and
analysis scripts; and use the connected microphone, scope, camera, Hall/FG, telemetry, and Kasa
power evidence. Routine candidate choices and repeat runs do not require additional permission.

Autonomy does not permit bypassing a hardware protection, exceeding the released 50--170 RPM range,
changing direction before verified stop, continuing after loss of human observation or the cutoff,
or guessing through a physical probe or mechanical intervention. Codex owns all software and
instrument automation; Michael performs only unavoidable physical hookups and the later damping and
housing installation, with one-step instructions when needed.

- Use the Razer Seiren V3 Mini or equivalent raw 24-bit/96 kHz USB condenser on an independent
  support, close to the motor but just outside the future housing envelope. Aim the front/logo face
  at the motor or nearest future opening. Keep gain, orientation, and room position fixed from the
  exposed golden baseline through the completed-housing capture; record stopped-room baselines and
  lossless WAV.
- At the start of the instrumented session, synchronize microphone audio, SOX plus FG/SPEED or VM24,
  supervisor telemetry, Hall/FG, and Kasa power. Capture the untouched current golden image with the
  dedicated mic fixed at the close-motor position **before changing any setting**. Confirm the
  captures are usable before beginning candidate work; the source baseline cannot be reconstructed
  honestly afterward.
- Set up the available camera for startup and the intermittent chirp. It is useful for detecting
  rough align/open-loop/handoff motion, visible contact, and rotor-position correlation. Hall/FG
  already establish steady-state stability, so video is not required for every acoustic plateau;
  omit it from ordinary steady-state captures. The dedicated microphone is the only acoustic
  authority. Camera audio may remain enabled solely to align video frames with dedicated-mic audio;
  never use it to compare candidates.
- First qualify scope frame timing and retain raw samples plus sidecar metadata. Use the synchronized
  evidence to distinguish electrical/commutation tones from mechanical radiation and to correlate
  transient chirps with SOX/current distortion, command transitions, or rotor position.
- Continue recording and judging every audible noise mode. During exposed source tuning, prioritize
  the intermittent chirp and rough startup sequence, then persistent narrowband tones that track
  PWM, commutation, electrical frequency, or current distortion. Capture broadband blade/airflow
  noise in the same ladder so it is not hidden, while treating it as a controller-tuning target only
  if synchronized evidence shows that a drive candidate changes it.
- Candidate order: characterize the reference; separate the steady electrical whine from transient
  chirps; localize the chirp; inspect startup current and handoff; compare startup parameters; then
  compare steady-state PWM/commutation candidates at matched measured speeds. Continue until every
  meaningful safe parameter family has either improved the result or been rejected by evidence and
  further changes produce no measurable improvement. Commit a new golden image only after the
  selected candidate repeats the low-speed starts, acoustic ladder, stop, persistence, both-direction
  behavior, and applicable endurance and fault checks.
- Keep the dedicated microphone fixed after the exposed finalist capture. Install the motor damping
  and completed upper housing with its interior damping without changing the controller tune, then
  repeat the close-mic acoustic ladder plus final mechanical and thermal qualification. Resume
  controller tuning only if the completed assembly exposes an objectionable sound that synchronized
  evidence ties to the controller. Skip a formal bed-position microphone capture; Michael's direct
  listening from bed is the final subjective acceptance check.
- Run loaded MPET as a captured comparison only, never as an automatic EEPROM replacement. Promote
  a candidate only if it improves the matched acoustic result and repeats all release checks.

### Prepared acquisition path

The pre-hardware automation is ready as of 2026-08-26. `09-run-loaded-profile.sh` validates and
runs `51-loaded-golden-baseline.txt` in verified-golden mode, rejects configuration mutation and
speeds outside 50--170 RPM, records the fixed microphone at 24-bit/96 kHz, captures timestamped
discrete OWON frames, and bundles camera, controller, Hall/FG, Kasa, audio, and scope evidence in a
hashed manifest. Its hardware-free validation and simulated scope path pass. Static physical
preflight on 2026-08-28 qualified the commissioning USB hub, Kasa control and metering, Ubiquiti G4
Instant stream at 1280x720/30 fps, Razer microphone at mono 24-bit/96 kHz without clipping, and
VDS1022I discrete frames at about 249,940 sample/s. The connected FG probe measured 3.24--3.32 V
after moving the 5 V-range offset from 0.5 to 0.2; 0.5 had clipped the high at 2.5 V. No physical
baseline has been recorded. The installed firmware could not read the MCF8316D during this preflight,
so dynamic SOX/FG response, camera-guard tracking, and cross-source timing remain open until the
physical controller-power path is confirmed and a bounded motion shakedown passes.

The baseline entry point intentionally cannot mutate the loaded golden image. After the untouched
reference is secured, `10-run-loaded-candidate.sh` can run a matched profile against one named
golden-derived volatile override. The initial allowlist covers PWM frequency, dead-time compensation,
and gate slew rate. Firmware restores and verifies the entire loaded image before applying the one
masked field, reports the distinct `tuning` verdict, watches the field for shadow reset, and provides
no EEPROM commit path. It also keeps the unloaded dynamic-current profile inactive, preserving a
true one-variable comparison. Arbitrary raw register writes remain non-runnable. Startup and other
parameter families should receive similarly narrow named candidates only after the synchronized
baseline identifies a reason to test them.

This candidate mechanism has passed host simulation, all-candidate golden/readback checks, profile
validation, clippy, and the embedded app build. It has not been flashed or exercised on the installed
controller yet, and no physical or acoustic conclusion follows from the software-only result.

The loaded-tuning goal is paused at Michael's direction until the full observability suite is
available. This is an evidence boundary, not an operating-permission boundary: while the room is
clear and Michael is continuously watching with the physical cutoff, bounded flashing and tests are
authorized if they do not draw acoustic or performance conclusions without the missing instruments
and the currently active provisional firmware is restored afterward.

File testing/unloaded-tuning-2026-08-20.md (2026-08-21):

# Unloaded motor tuning, 2026-08-20

This is the retained evidence for the restrained bare GL100 commissioning campaign. The motor
area was clear and continuously monitored with an immediate physical cutoff. A 30 fps IR camera
tracked the unique radial arm while precise Hall edge timing, MCF FG, and Kasa wall power were
logged concurrently. Hall is the shaft-speed authority above 140 RPM: the flexible outer
magnet/tape stick and even the inner optical line have orientation-specific tracking slips at
high speed. The camera remains the independent authority for gross motion, direction, stalls,
and synchronized audio. Earlier 19.4 V DPS-150 results remain below as supporting history.
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

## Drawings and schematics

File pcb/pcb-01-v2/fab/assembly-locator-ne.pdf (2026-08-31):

# PCB-01 V2 assembly locator, NE

Revision V2 | component-side (top) view | coordinates in mm | generated from current .kicad_pcb

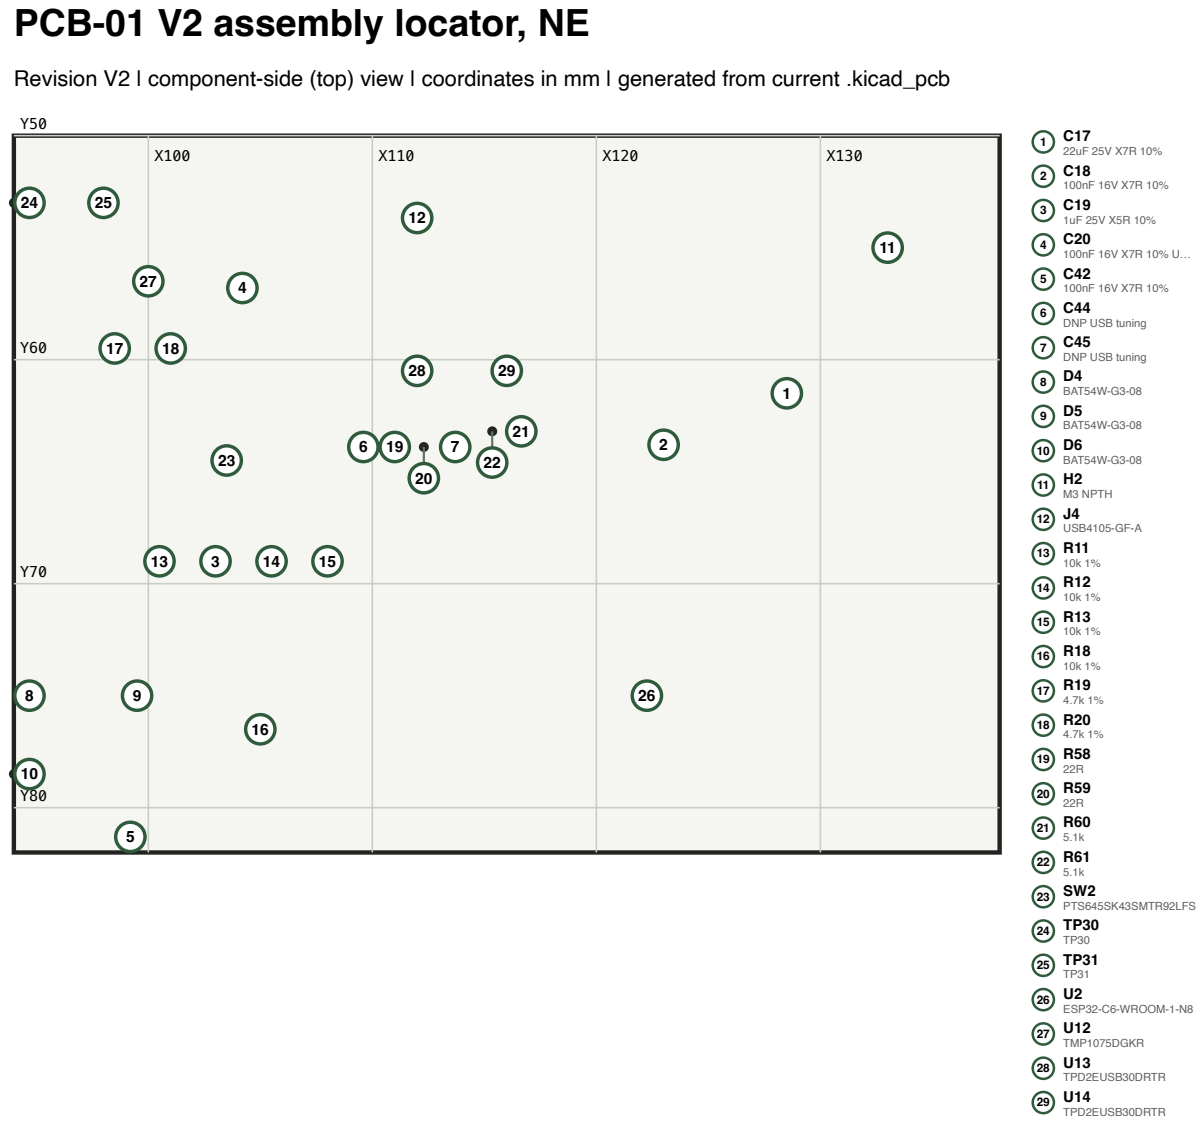
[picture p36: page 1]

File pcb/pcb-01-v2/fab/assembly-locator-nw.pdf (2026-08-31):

# PCB-01 V2 assembly locator, NW

Revision V2 | component-side (top) view | coordinates in mm | generated from current .kicad_pcb

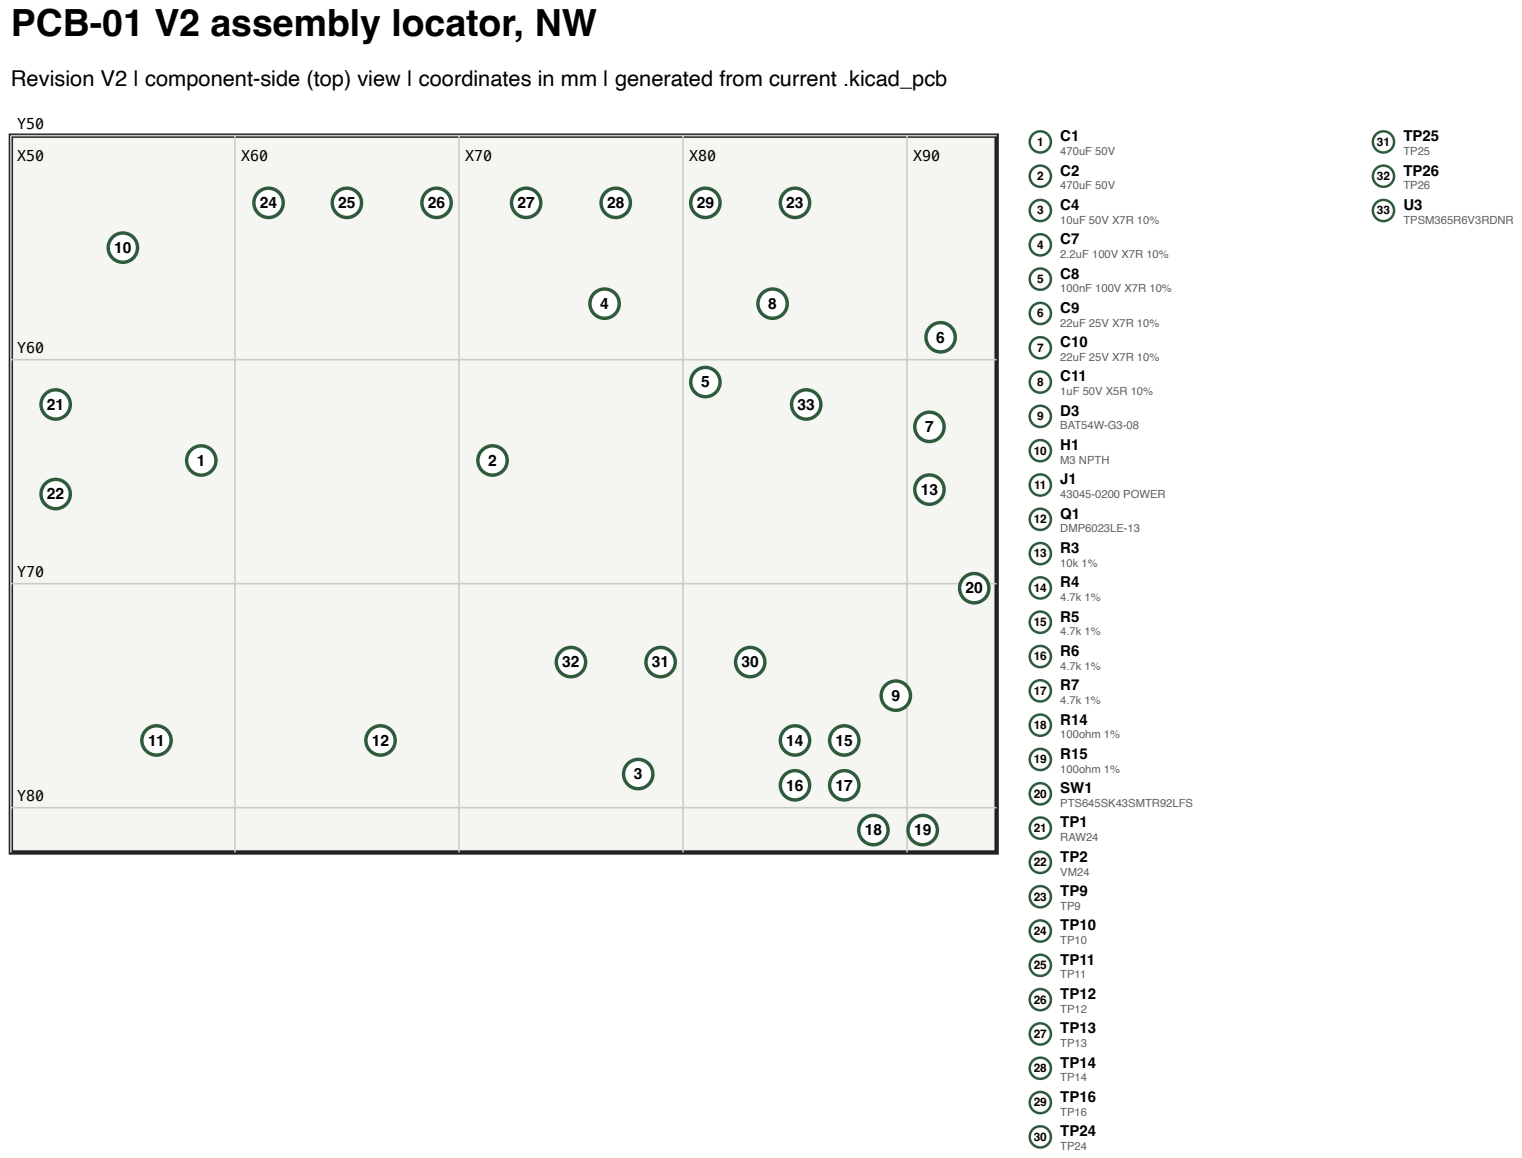
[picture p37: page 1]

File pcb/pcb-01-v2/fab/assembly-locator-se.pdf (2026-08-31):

# PCB-01 V2 assembly locator, SE

# Revision V2

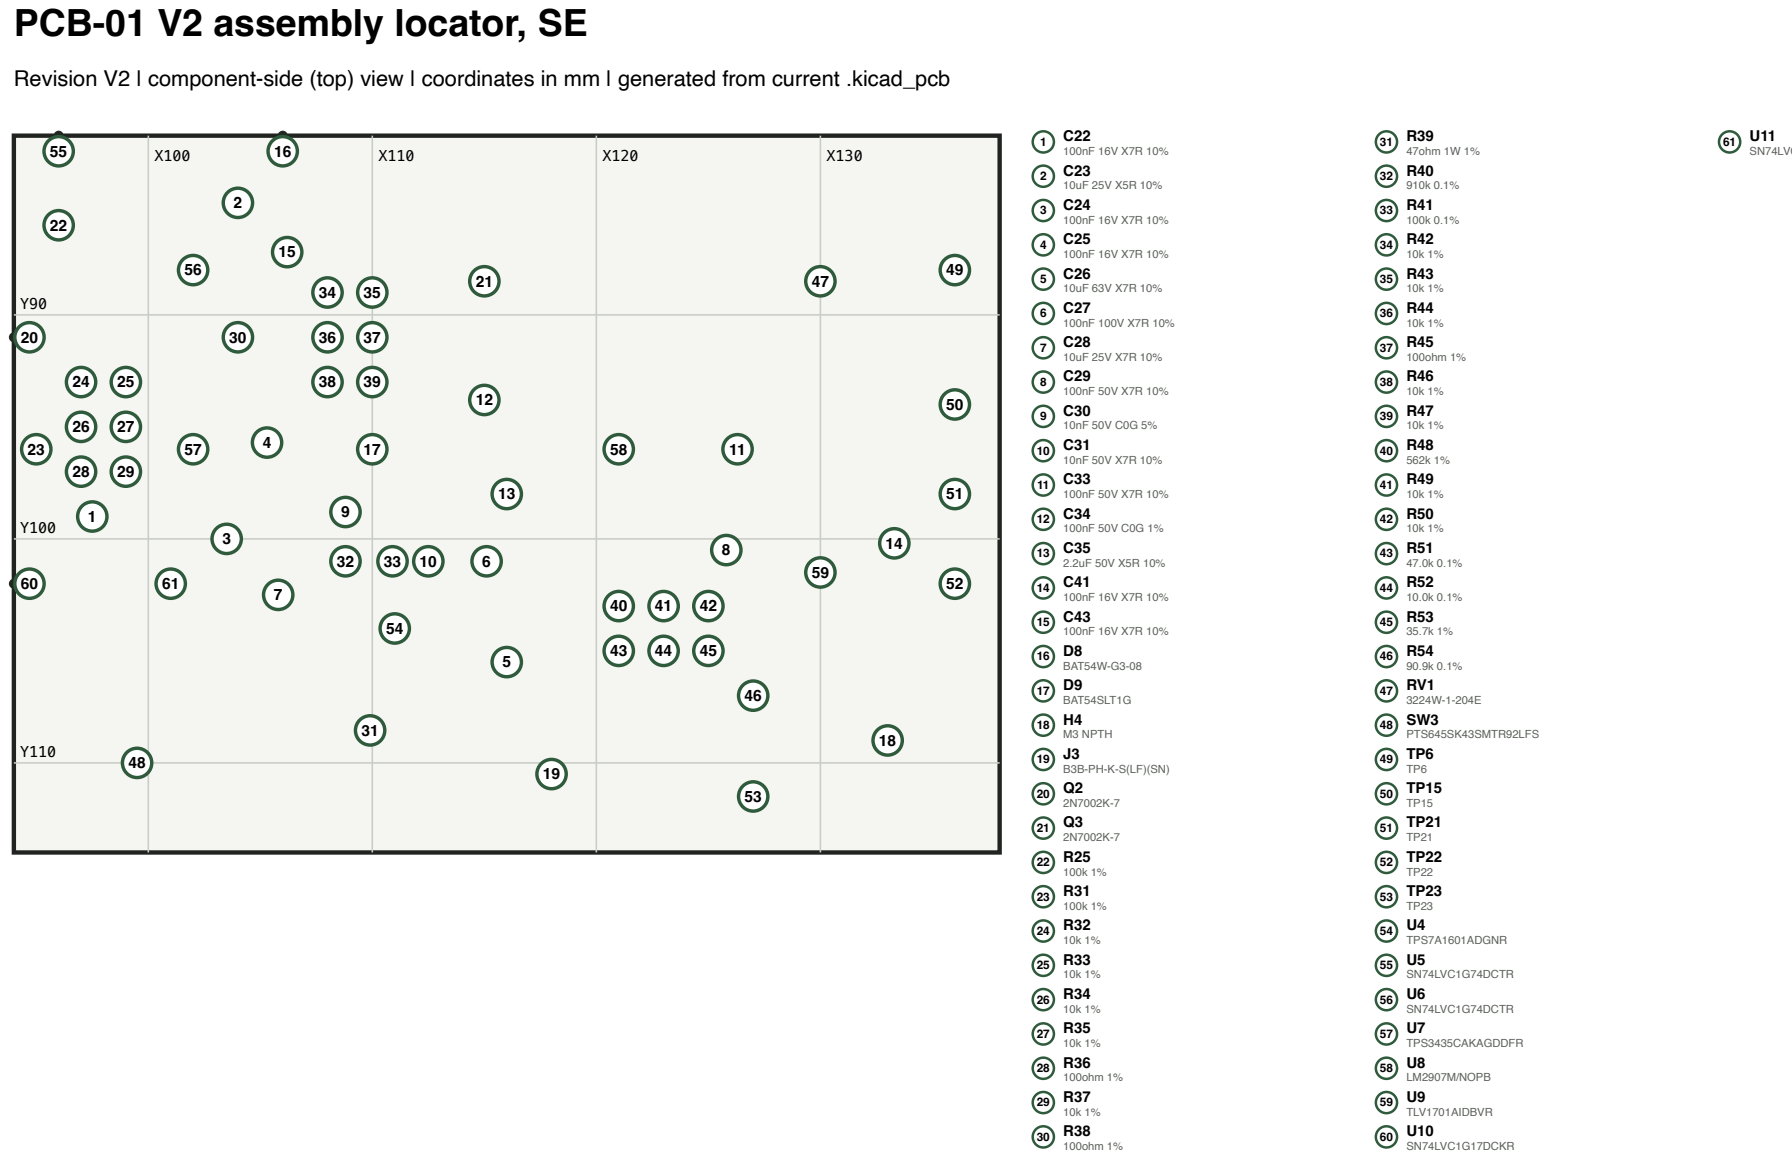
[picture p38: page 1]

component-side (top) view

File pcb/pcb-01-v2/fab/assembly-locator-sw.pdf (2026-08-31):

# PCB-01 V2 assembly locator, SW

Revision V2 | component-side (top) view | coordinates in mm | generated from current .kicad_pcb

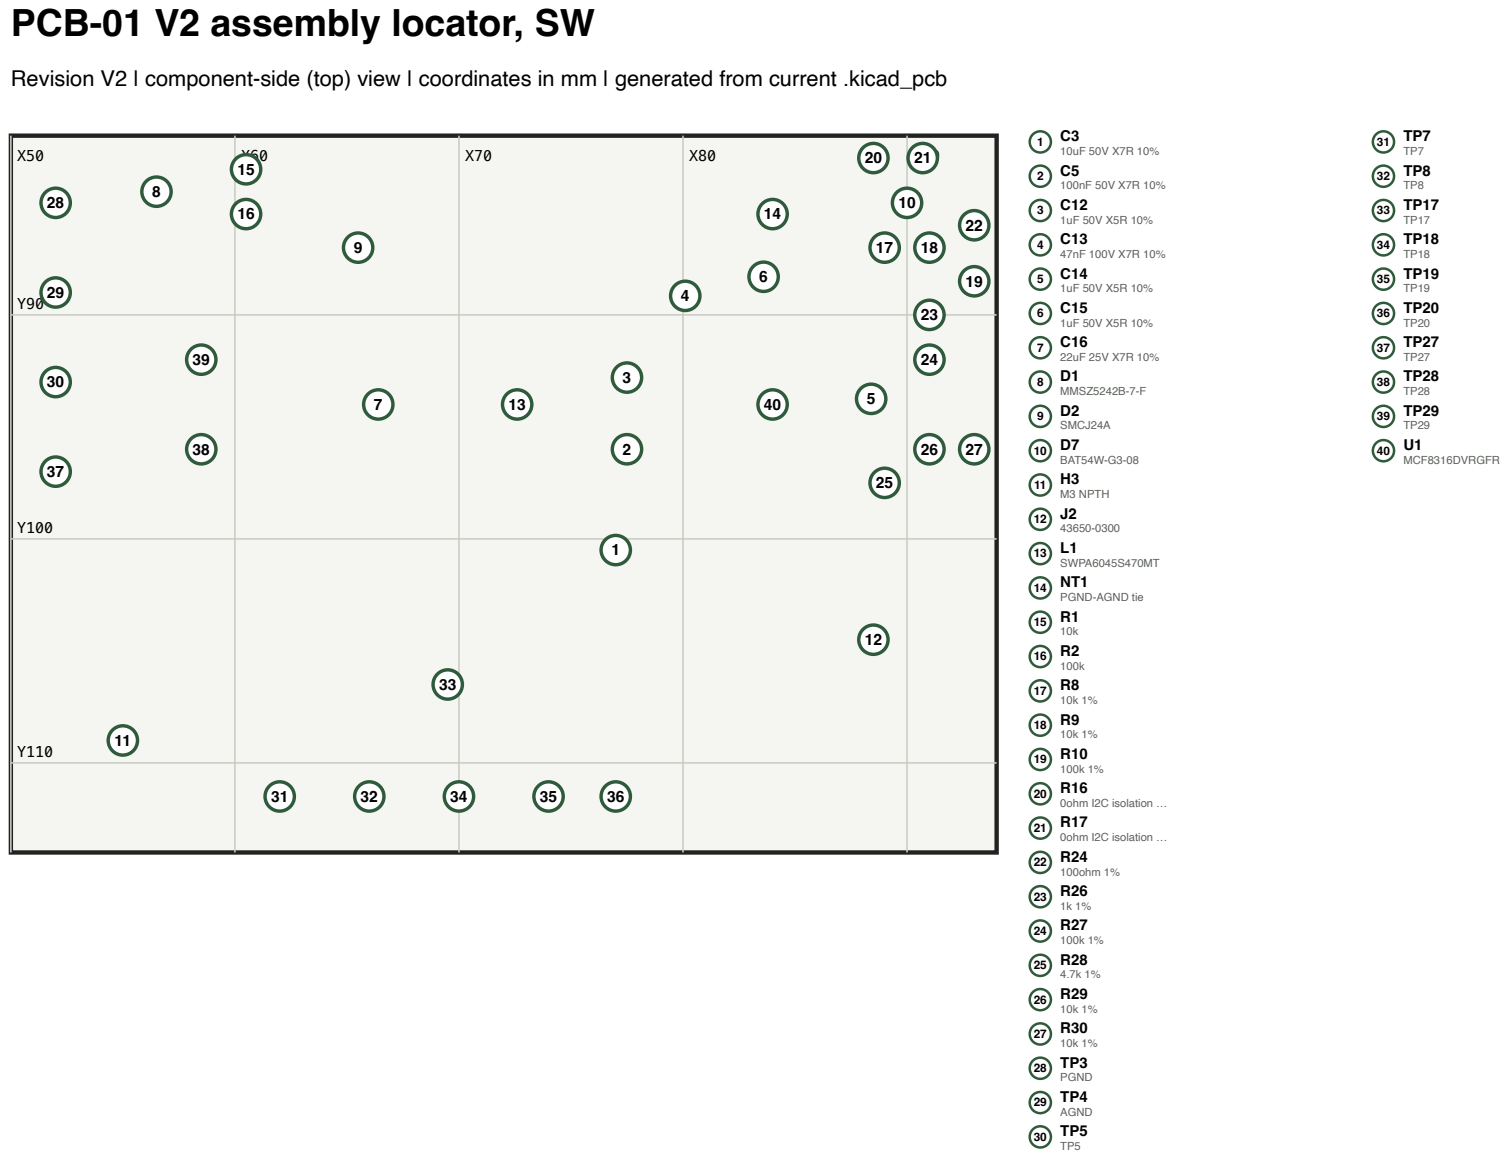
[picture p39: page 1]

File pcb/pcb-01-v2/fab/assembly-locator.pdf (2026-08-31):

# PCB-01 V2 assembly locator, NW

Revision V2 | component-side (top) view | coordinates in mm | generated from current .kicad_pcb


# PCB-01 V2 assembly locator, NE

Revision V2 | component-side (top) view | coordinates in mm | generated from current .kicad_pcb


# PCB-01 V2 assembly locator, SW

Revision V2 | component-side (top) view | coordinates in mm | generated from current .kicad_pcb


# PCB-01 V2 assembly locator, SE

# Revision V2


component-side (top) view

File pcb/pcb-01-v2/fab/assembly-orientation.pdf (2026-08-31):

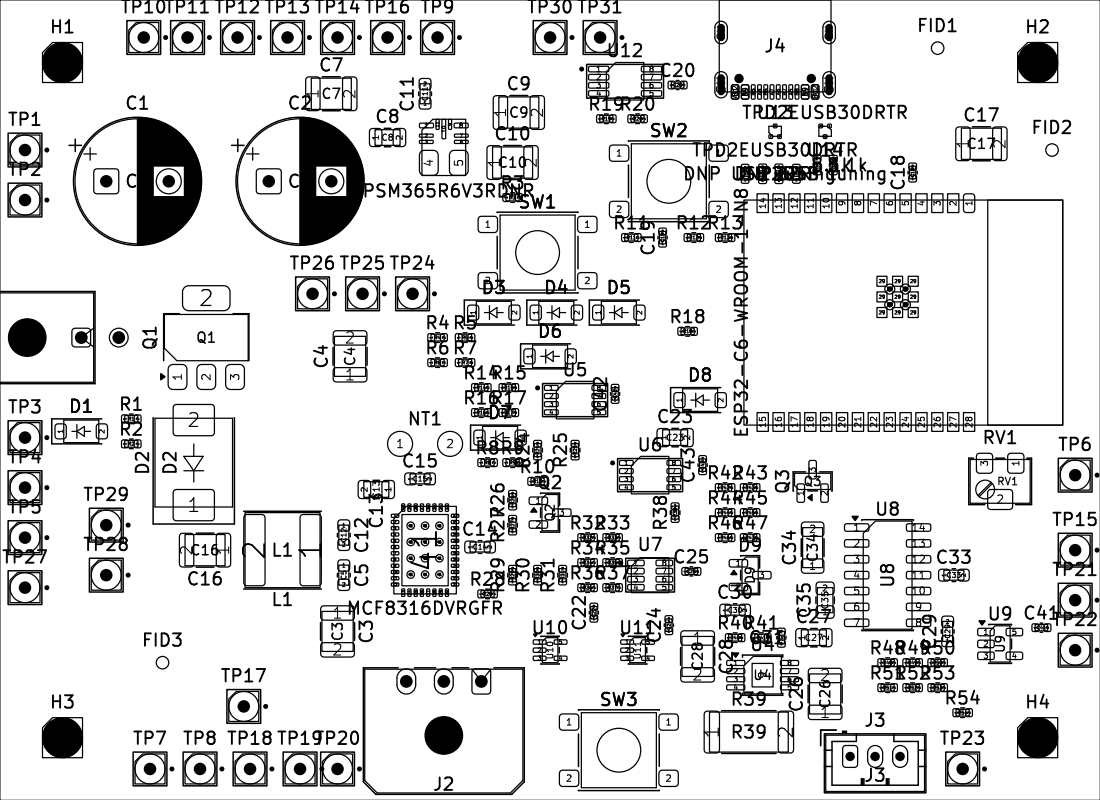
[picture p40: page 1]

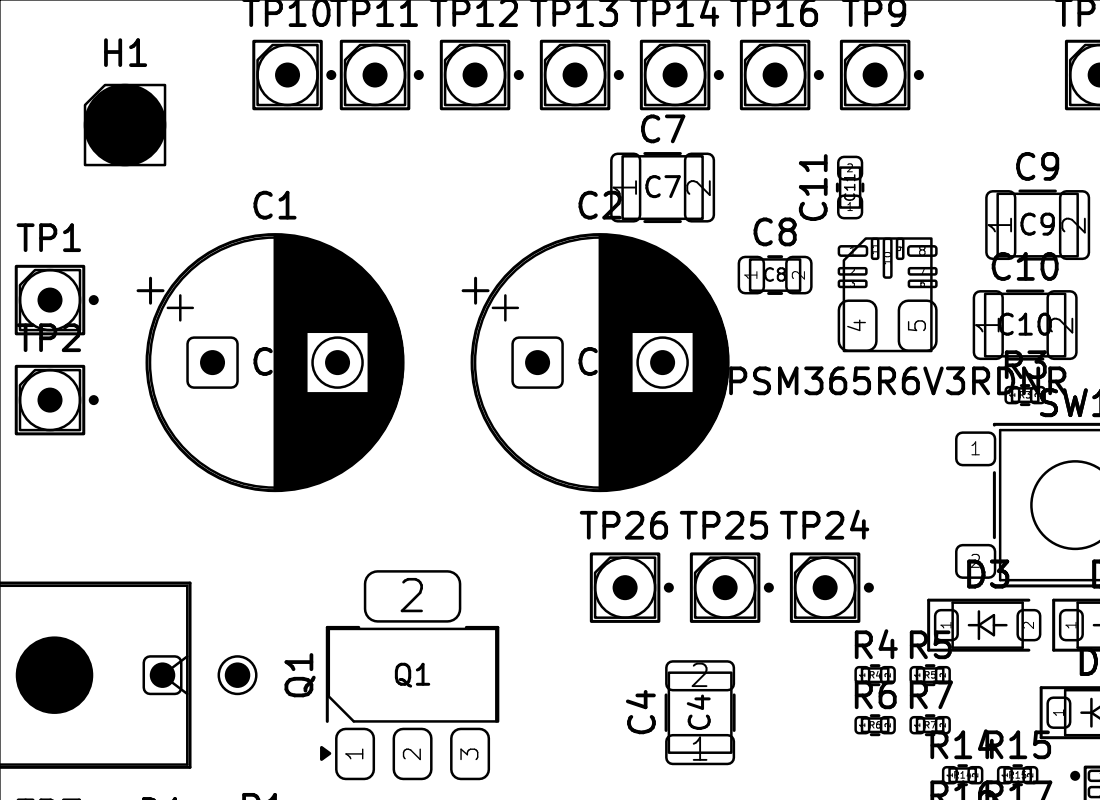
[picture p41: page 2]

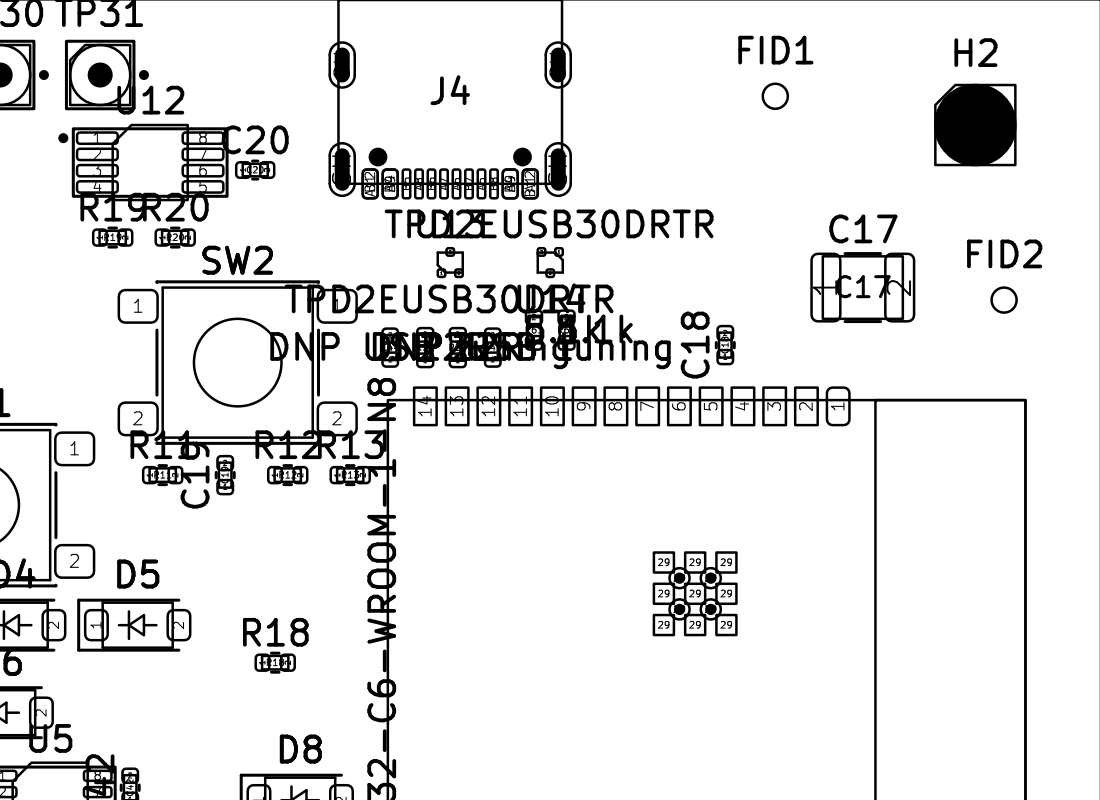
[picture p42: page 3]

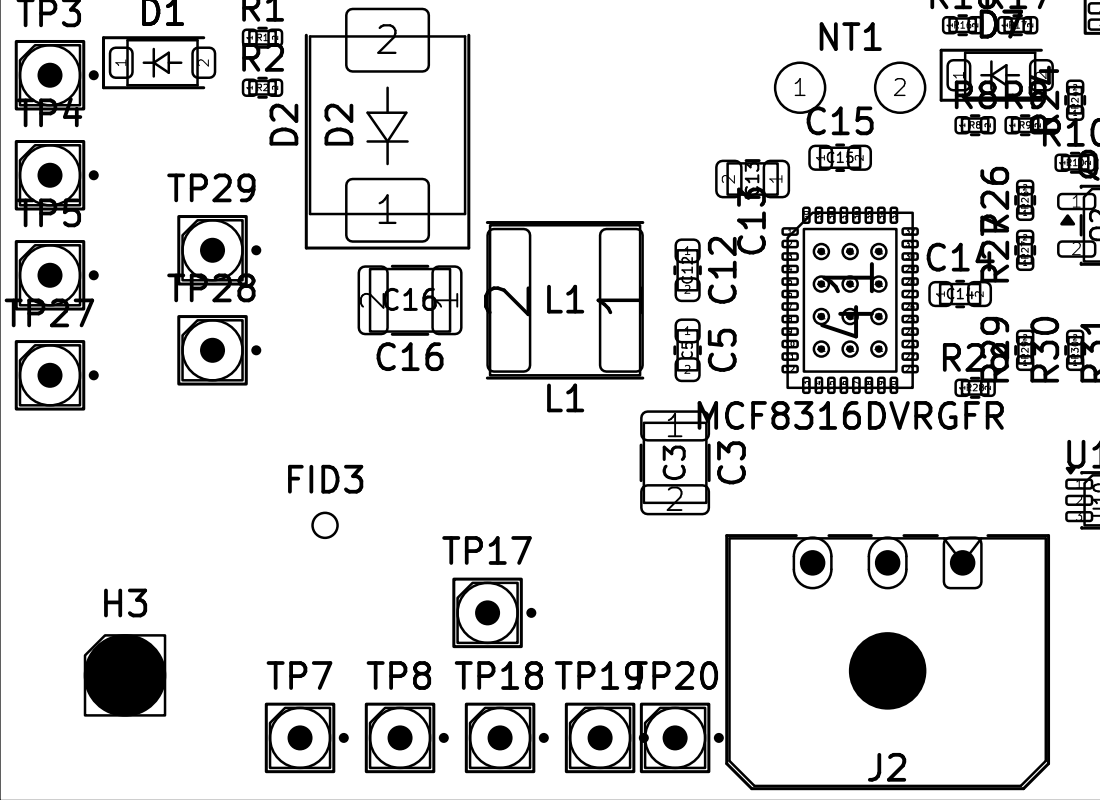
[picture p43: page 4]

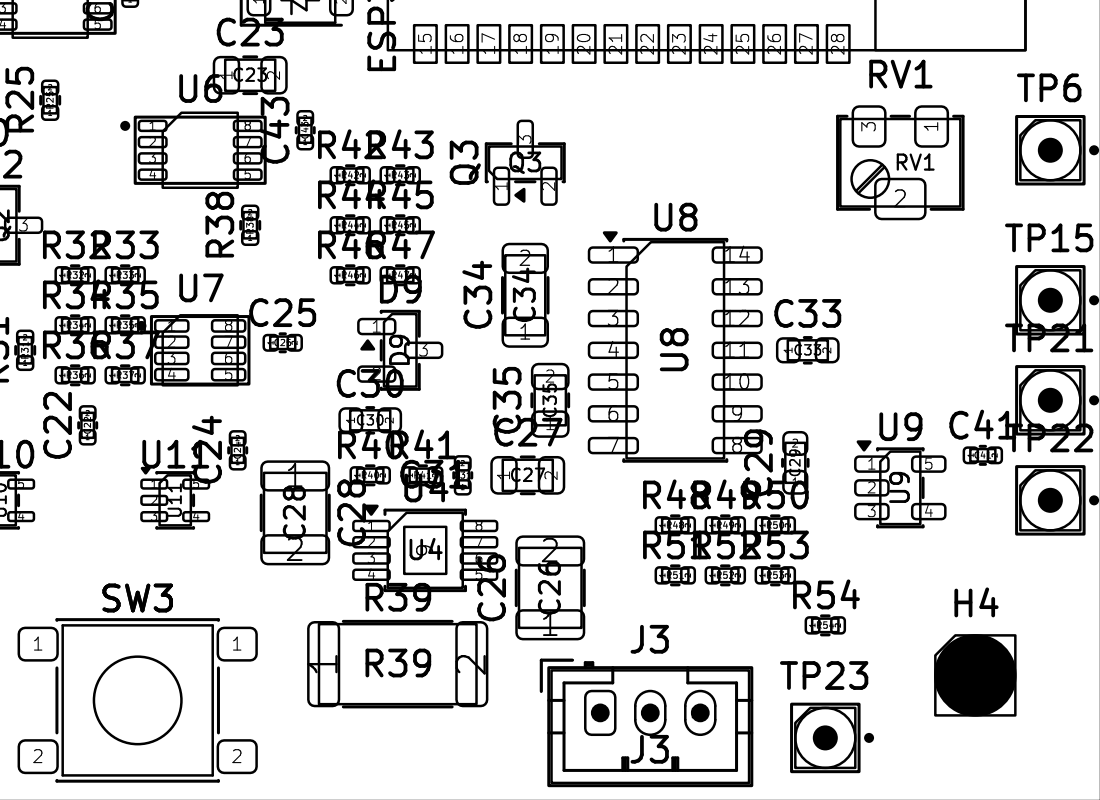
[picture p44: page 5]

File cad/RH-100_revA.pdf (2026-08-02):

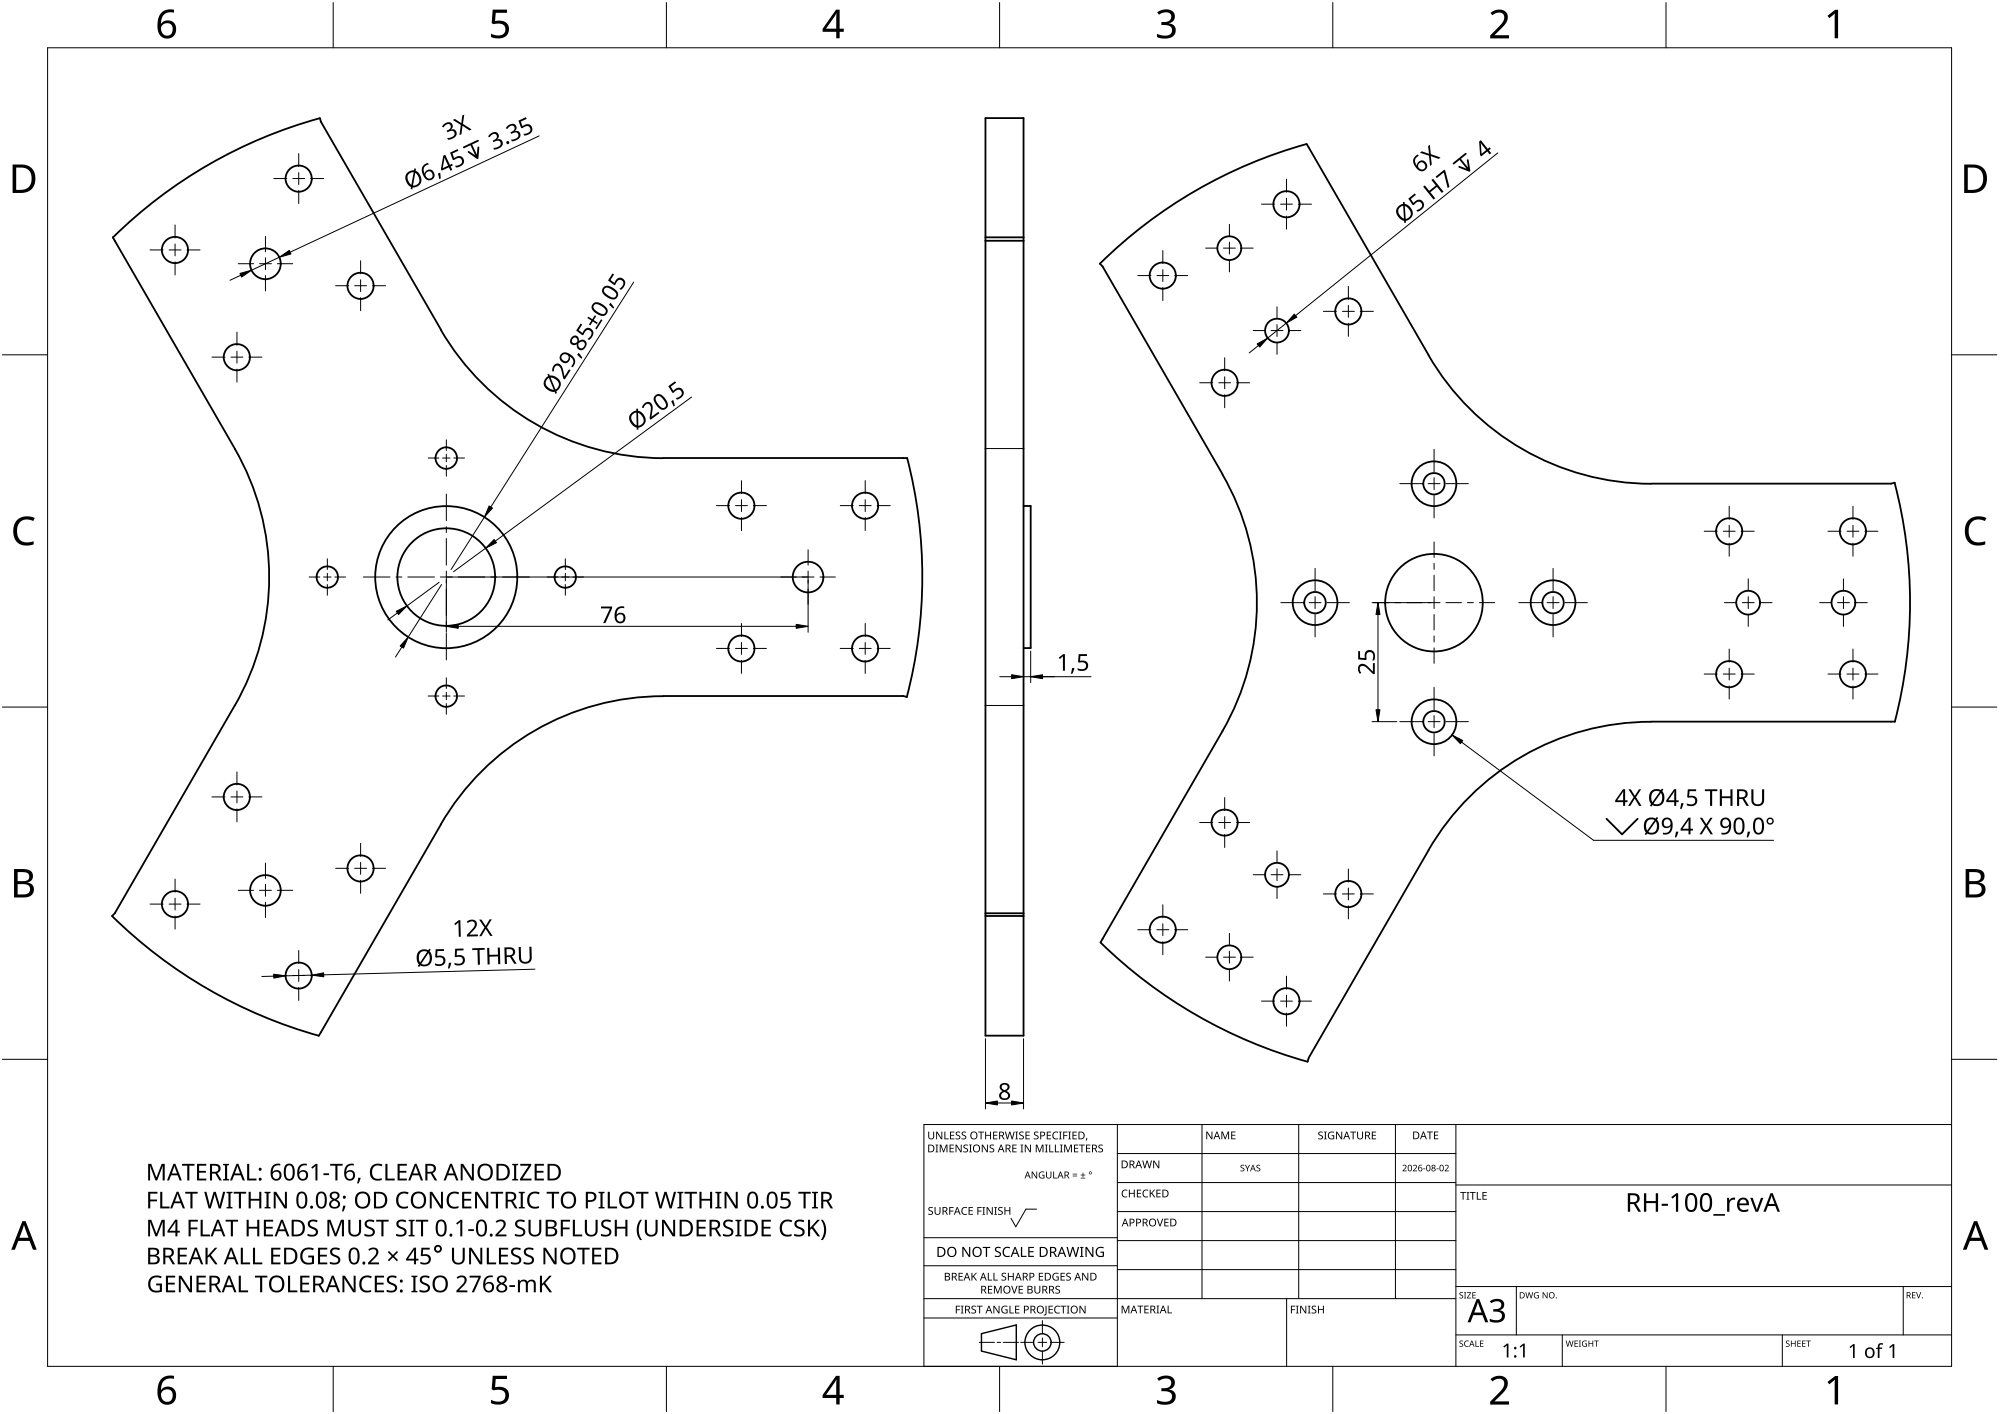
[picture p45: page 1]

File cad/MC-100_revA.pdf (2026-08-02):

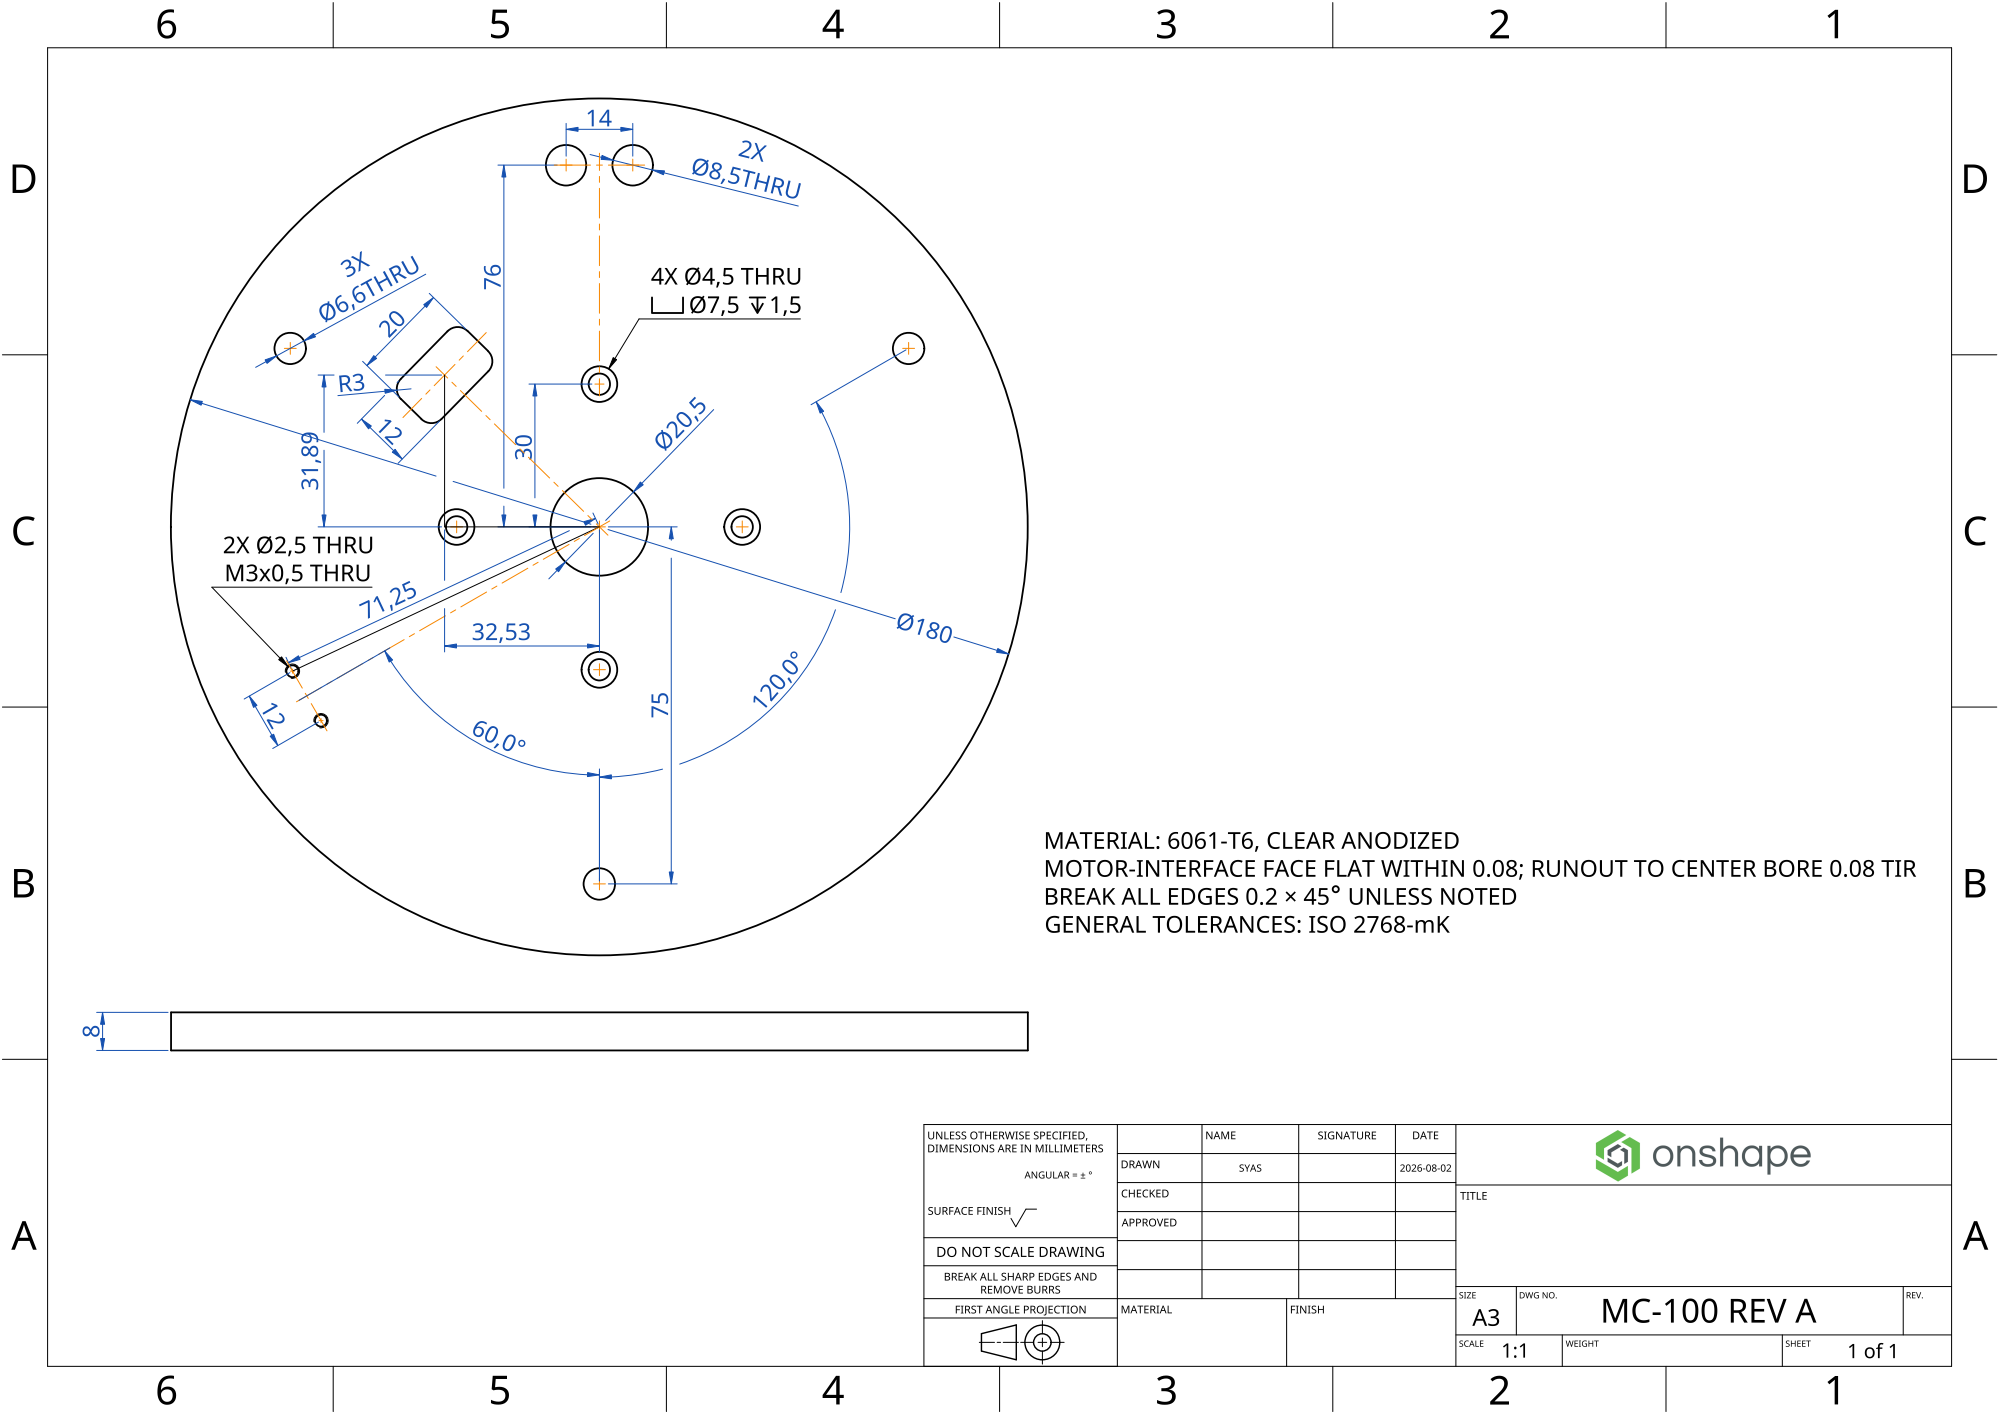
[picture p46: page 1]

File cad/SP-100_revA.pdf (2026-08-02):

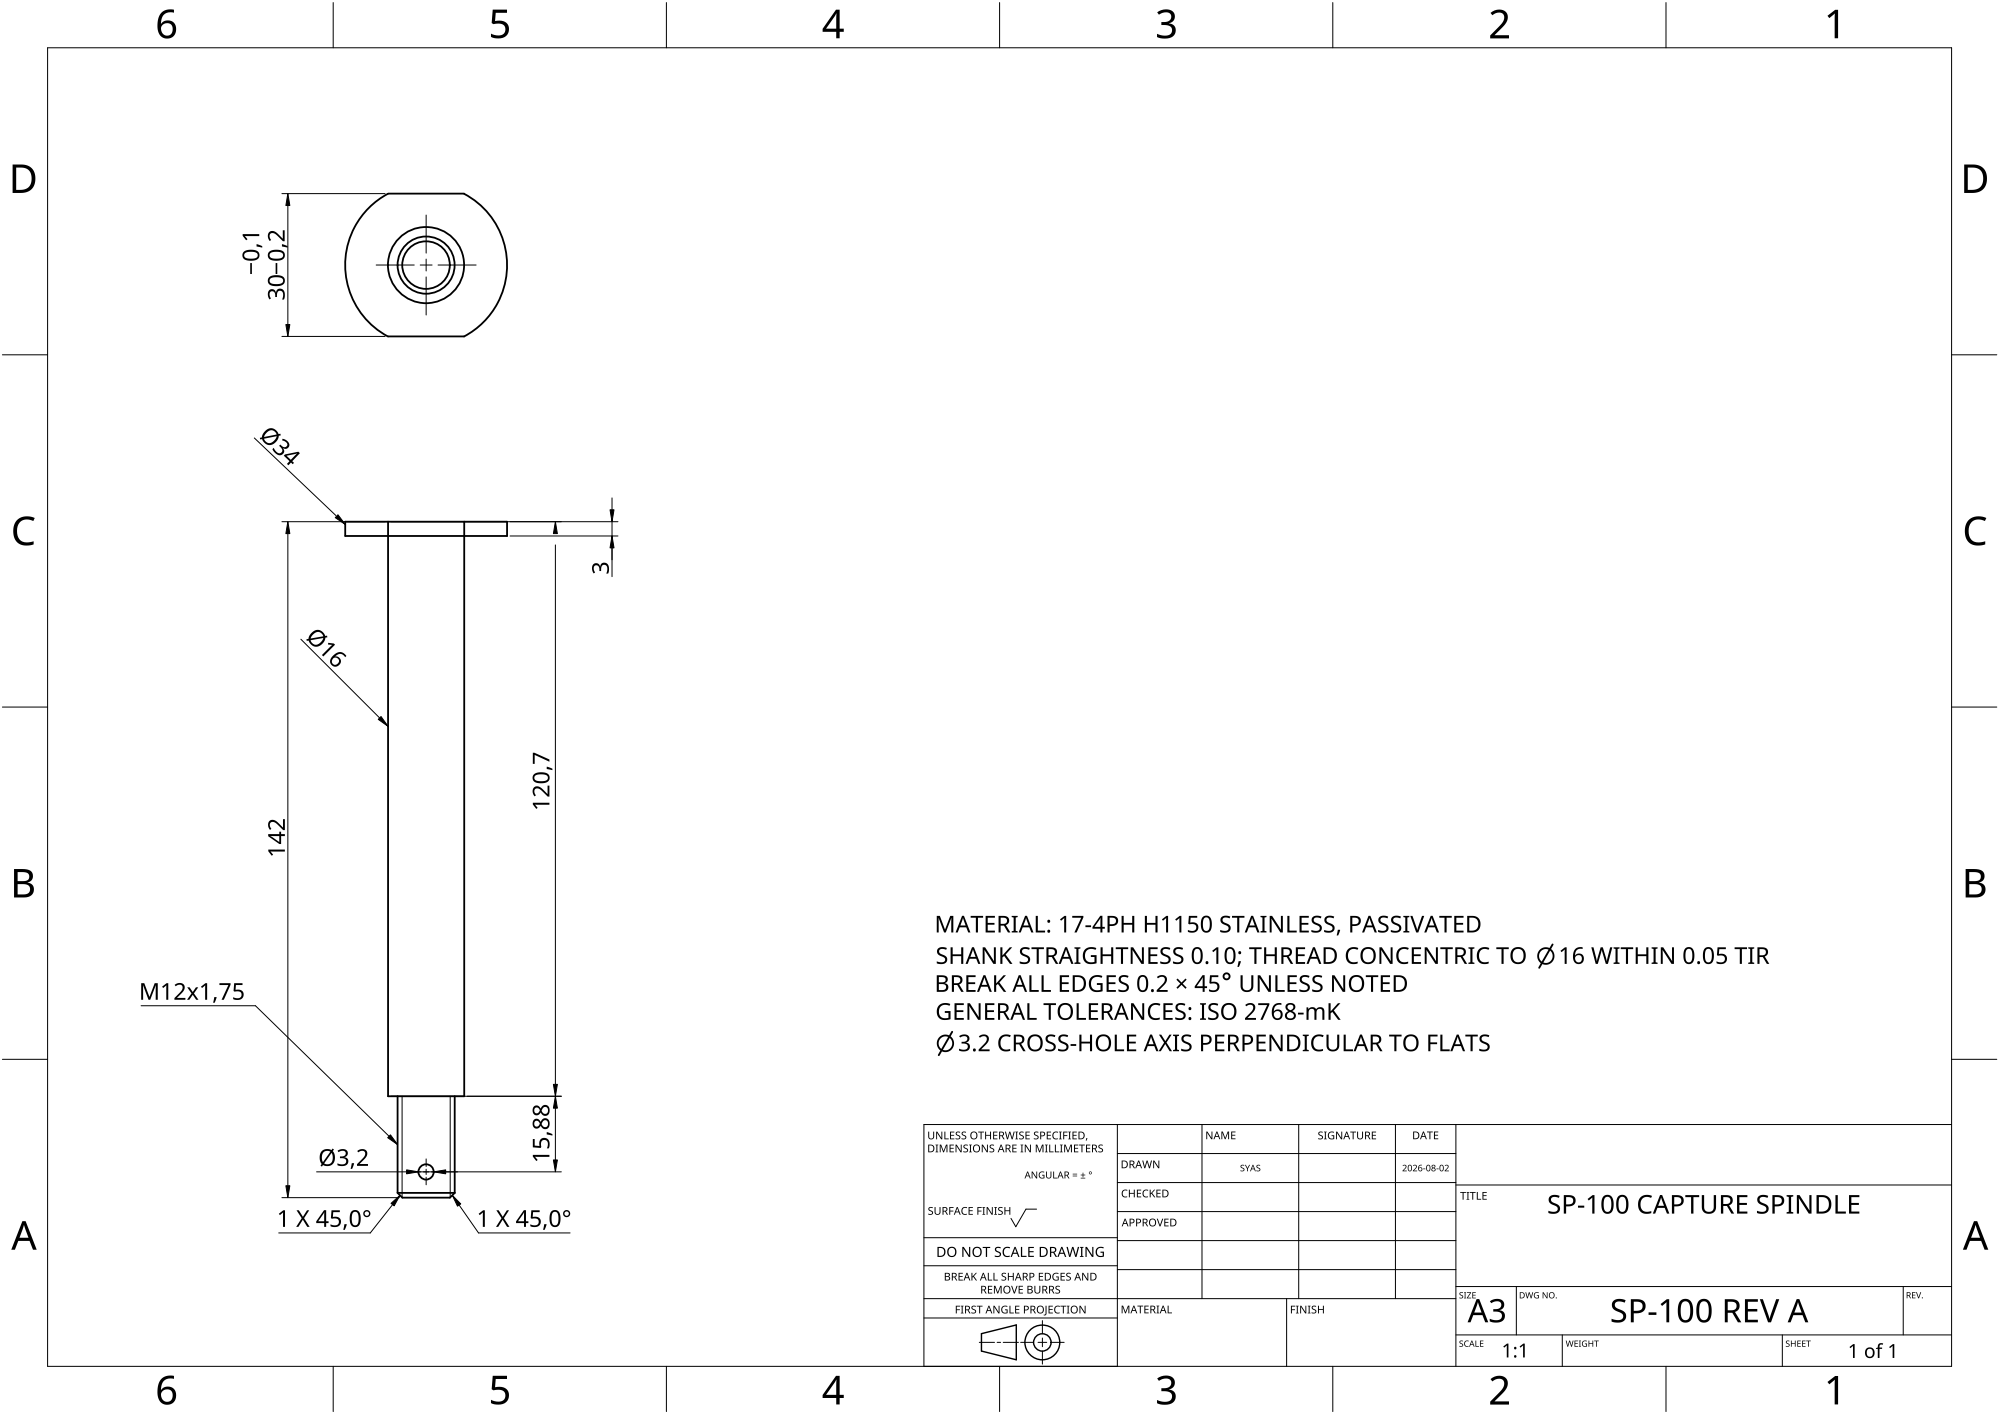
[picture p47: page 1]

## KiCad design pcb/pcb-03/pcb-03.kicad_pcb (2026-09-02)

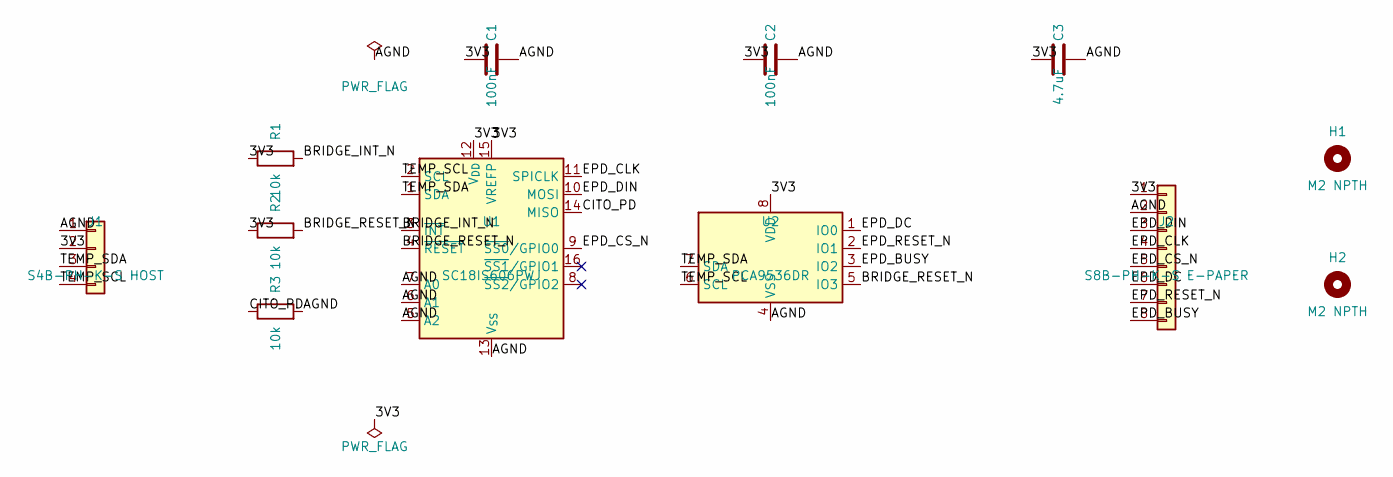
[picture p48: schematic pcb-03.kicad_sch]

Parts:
C1, C2: 100nF; C_0603_1608Metric; MPN C0603C104K5RACTU
C3: 4.7uF; C_0603_1608Metric; MPN EMK107ABJ475KA-T
H1, H2: M2 NPTH; MountingHole_2.2mm_M2
J1: S4B-PH-K-S HOST; JST_PH_S4B-PH-K_1x04_P2.00mm_Horizontal; MPN S4B-PH-K-S
J2: S8B-PH-K-S E-PAPER; JST_PH_S8B-PH-K_1x08_P2.00mm_Horizontal; MPN S8B-PH-K-S
R1, R2, R3: 10k; R_0603_1608Metric; MPN PTN0603Y1002BST1
U1: SC18IS606PWJ; TSSOP-16_4.4x5mm_P0.65mm; MPN SC18IS606PWJ
U2: PCA9536DR; SOIC-8_3.9x4.9mm_P1.27mm; MPN PCA9536DR

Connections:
/3V3: C1.1, C2.1, C3.1, J1.2, J2.1, R1.1, R2.1, U1.12 (V_{DD}), U1.15 (VREFP), U2.8 (VDD)
/AGND: C1.2, C2.2, C3.2, J1.1, J2.2, R3.2, U1.5 (A2), U1.6 (A1), U1.7 (A0), U1.13 (V_{SS}), U2.4 (VSS)
/BRIDGE_INT_N: R1.2, U1.3 (~INT)
/BRIDGE_RESET_N: R2.2, U1.4 (~RESET), U2.5 (IO3)
/CITO_PD: R3.1, U1.14 (MISO)
/EPD_BUSY: J2.8, U2.3 (IO2)
/EPD_CLK: J2.4, U1.11 (SPICLK)
/EPD_CS_N: J2.5, U1.9 (~SS0/GPIO0)
/EPD_DC: J2.6, U2.1 (IO0)
/EPD_DIN: J2.3, U1.10 (MOSI)
/EPD_RESET_N: J2.7, U2.2 (IO1)
/TEMP_SCL: J1.4, U1.2 (SCL), U2.6 (SCL)
/TEMP_SDA: J1.3, U1.1 (SDA), U2.7 (SDA)

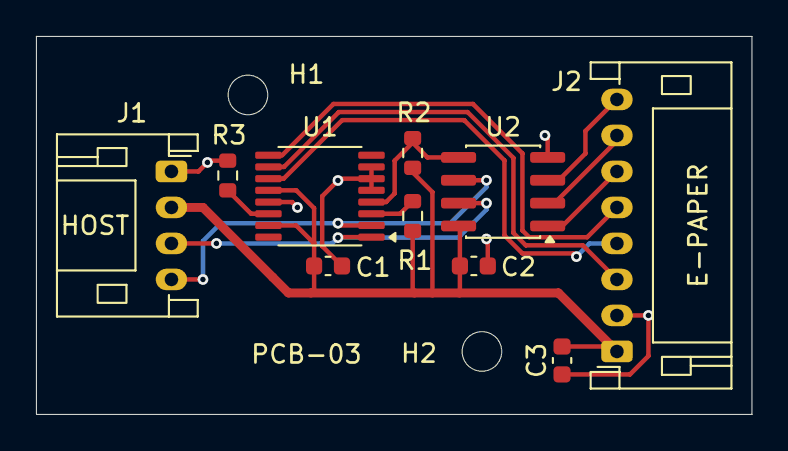
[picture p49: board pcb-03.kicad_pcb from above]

Board: 2 copper layers, 39.8 x 21.0 mm, 12 parts (0 on the bottom side), 13 nets.

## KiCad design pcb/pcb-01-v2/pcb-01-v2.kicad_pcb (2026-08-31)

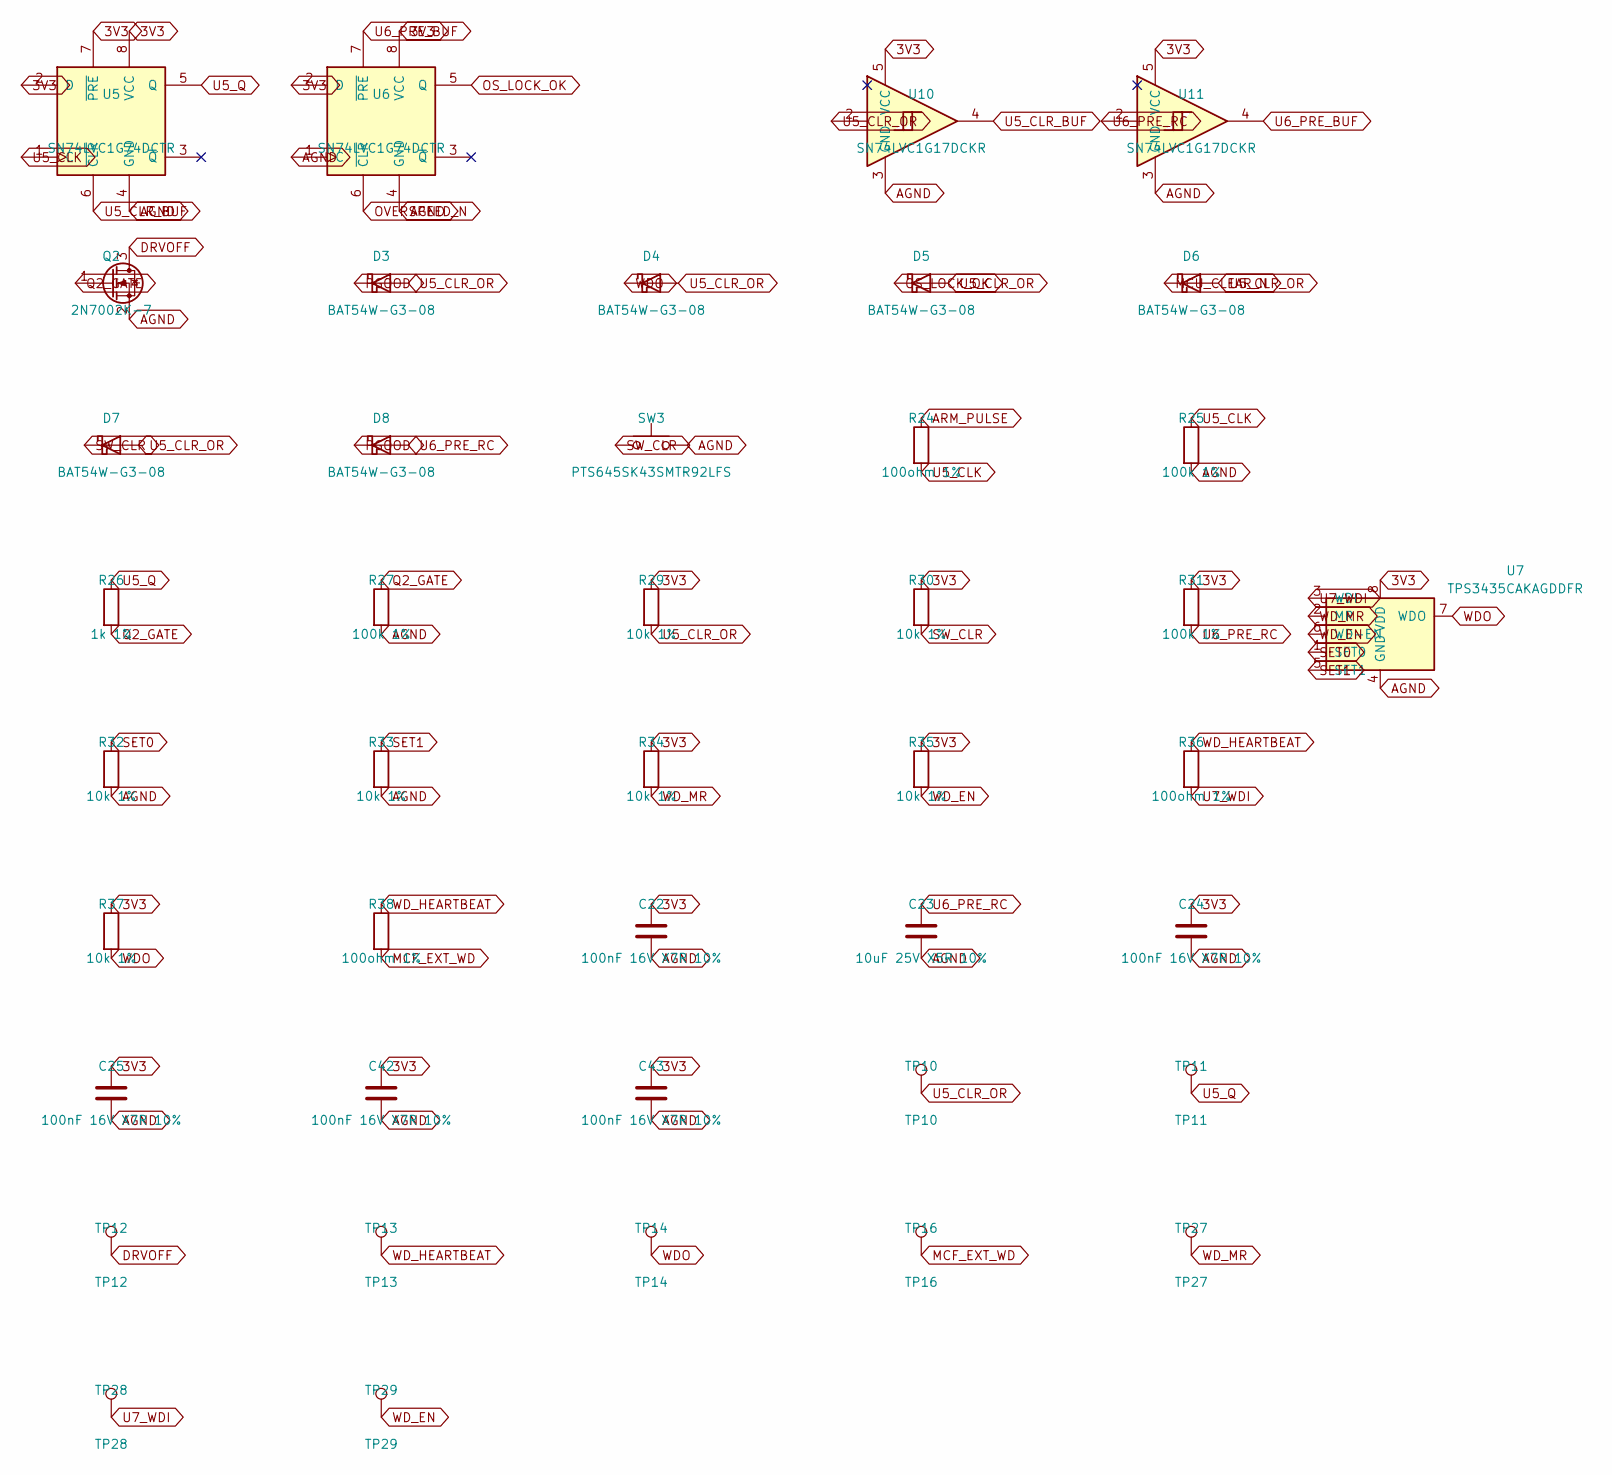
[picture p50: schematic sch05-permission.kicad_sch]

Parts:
C22, C24, C25, C42, C43: 100nF 16V X7R 10%; C_0402_1005Metric
C23: 10uF 25V X5R 10%; C_0805_2012Metric
D3, D4, D5, D6, D7, D8: BAT54W-G3-08; D_SOD-123
Q2: 2N7002K-7; SOT-23
R24, R36, R38: 100ohm 1%; R_0402_1005Metric
R25, R27, R31: 100k 1%; R_0402_1005Metric
R26: 1k 1%; R_0402_1005Metric
R29, R30, R32, R33, R34, R35, R37: 10k 1%; R_0402_1005Metric
SW3: PTS645SK43SMTR92LFS; SW_SPST_PTS645Sx43SMTR92
TP10: TP10; TestHole_2.4mm_PTH1.0mm
TP11: TP11; TestHole_2.4mm_PTH1.0mm
TP12: TP12; TestHole_2.4mm_PTH1.0mm
TP13: TP13; TestHole_2.4mm_PTH1.0mm
TP14: TP14; TestHole_2.4mm_PTH1.0mm
TP16: TP16; TestHole_2.4mm_PTH1.0mm
TP27: TP27; TestHole_2.4mm_PTH1.0mm
TP28: TP28; TestHole_2.4mm_PTH1.0mm
TP29: TP29; TestHole_2.4mm_PTH1.0mm
U5, U6: SN74LVC1G74DCTR; TI_SM8_DCT0008A
U7: TPS3435CAKAGDDFR; SOT-23-8_P0.65mm_Clearance0.20
U10, U11: SN74LVC1G17DCKR; SOT-353_SC-70-5

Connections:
3V3: C22.1, C24.1, C25.1, C42.1, C43.1, R29.1, R30.1, R31.1, R34.1, R35.1, R37.1, U5.2 (D), U5.7 (~PRE), U5.8 (VCC), U6.2 (D), U6.8 (VCC), U7.8 (VDD), U10.5 (VCC), U11.5 (VCC); also elsewhere on the board
ARM_PULSE: R24.1; also elsewhere on the board
DRVOFF: Q2.3 (D), TP12.1 (1_1); also elsewhere on the board
MCF_EXT_WD: R38.2, TP16.1 (1_1); also elsewhere on the board
MCU_CLEAR_N: D6.1 (K); also elsewhere on the board
OS_LOCK_OK: D5.1 (K), U6.5 (Q)
OVERSPEED_N: U6.6 (~CLR); also elsewhere on the board
PGOOD: D3.1 (K), D8.1 (K); also elsewhere on the board
Q2_GATE: Q2.1 (G), R26.2, R27.1
SET0: R32.1, U7.1 (SET0)
SET1: R33.1, U7.5 (SET1)
SW_CLR: D7.1 (K), R30.2, SW3.1
U5_CLK: R24.2, R25.1, U5.1 (C)
U5_CLR_BUF: U5.6 (~CLR), U10.4
U5_CLR_OR: D3.2 (A), D4.2 (A), D5.2 (A), D6.2 (A), D7.2 (A), R29.2, TP10.1 (1_1), U10.2
U5_Q: R26.1, TP11.1 (1_1), U5.5 (Q)
U6_PRE_BUF: U6.7 (~PRE), U11.4
U6_PRE_RC: C23.1, D8.2 (A), R31.2, U11.2
U7_WDI: R36.2, TP28.1 (1_1), U7.3 (WDI)
WDO: D4.1 (K), R37.2, TP14.1 (1_1), U7.7 (WDO); also elsewhere on the board
WD_EN: R35.2, TP29.1 (1_1), U7.6 (WD-EN)
WD_HEARTBEAT: R36.1, R38.1, TP13.1 (1_1); also elsewhere on the board
WD_MR: R34.2, TP27.1 (1_1), U7.2 (MR)

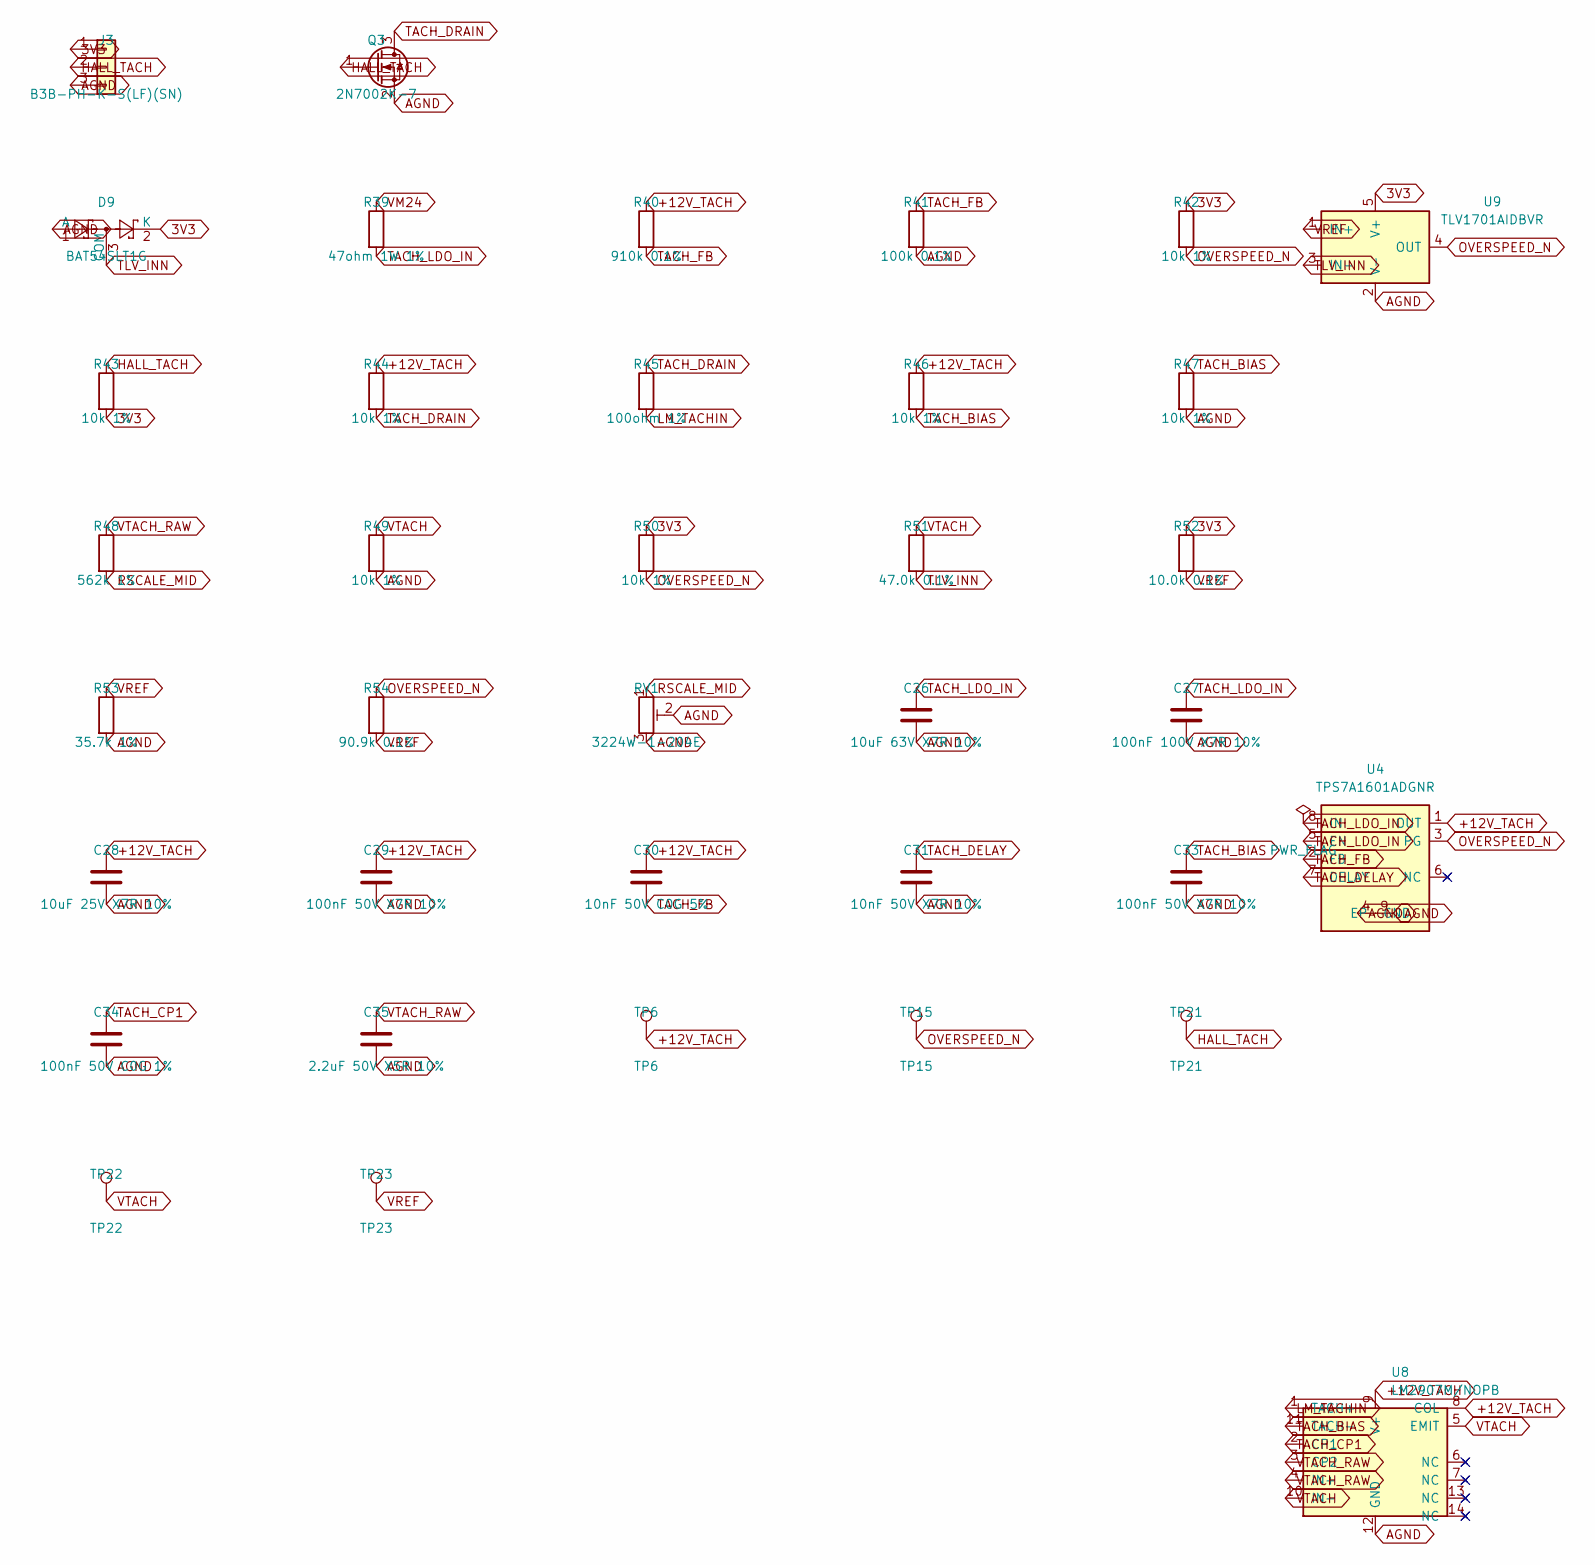
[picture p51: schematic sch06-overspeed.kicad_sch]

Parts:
C26: 10uF 63V X7R 10%; C_1210_3225Metric
C27: 100nF 100V X7R 10%; C_0805_2012Metric
C28: 10uF 25V X7R 10%; C_1210_3225Metric
C29, C33: 100nF 50V X7R 10%; C_0603_1608Metric
C30: 10nF 50V C0G 5%; C_0603_1608Metric
C31: 10nF 50V X7R 10%; C_0402_1005Metric
C34: 100nF 50V C0G 1%; C_1206_3216Metric
C35: 2.2uF 50V X5R 10%; C_0805_2012Metric
D9: BAT54SLT1G; SOT-23
J3: B3B-PH-K-S(LF)(SN); JST_PH_B3B-PH-K_1x03_P2.00mm_Vertical
Q3: 2N7002K-7; SOT-23
R39: 47ohm 1W 1%; R_2512_6332Metric
R40: 910k 0.1%; R_0402_1005Metric
R41: 100k 0.1%; R_0402_1005Metric
R42, R43, R44, R46, R47, R49, R50: 10k 1%; R_0402_1005Metric
R45: 100ohm 1%; R_0402_1005Metric
R48: 562k 1%; R_0402_1005Metric
R51: 47.0k 0.1%; R_0402_1005Metric
R52: 10.0k 0.1%; R_0402_1005Metric
R53: 35.7k 1%; R_0402_1005Metric
R54: 90.9k 0.1%; R_0402_1005Metric
RV1: 3224W-1-204E; Potentiometer_Bourns_3224W_Vertical
TP6: TP6; TestHole_2.4mm_PTH1.0mm
TP15: TP15; TestHole_2.4mm_PTH1.0mm
TP21: TP21; TestHole_2.4mm_PTH1.0mm
TP22: TP22; TestHole_2.4mm_PTH1.0mm
TP23: TP23; TestHole_2.4mm_PTH1.0mm
U4: TPS7A1601ADGNR; MSOP-8-1EP_3x3mm_P0.65mm_EP1.68x1.88mm
U8: LM2907M/NOPB; SOIC-14_3.9x8.7mm_P1.27mm
U9: TLV1701AIDBVR; SOT-23-5

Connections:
3V3: D9.2 (K), J3.1, R42.1, R43.2, R50.1, R52.1, U9.5 (V+); also elsewhere on the board
+12V_TACH: C28.1, C29.1, C30.1, R40.1, R44.1, R46.1, TP6.1 (1_1), U4.1 (OUT), U8.8 (COL), U8.9 (V+)
HALL_TACH: J3.2, Q3.1 (G), R43.1, TP21.1 (1_1); also elsewhere on the board
LM_TACHIN: R45.2, U8.1 (TACH+)
OVERSPEED_N: R42.2, R50.2, R54.1, TP15.1 (1_1), U4.3 (PG), U9.4 (OUT); also elsewhere on the board
RSCALE_MID: R48.2, RV1.1
TACH_BIAS: C33.1, R46.2, R47.1, U8.11 (TACH-)
TACH_CP1: C34.1, U8.2 (CP1)
TACH_DELAY: C31.1, U4.7 (DELAY)
TACH_DRAIN: Q3.3 (D), R44.2, R45.1
TACH_FB: C30.2, R40.2, R41.1, U4.2 (FB)
TACH_LDO_IN: C26.1, C27.1, R39.2, U4.5 (EN), U4.8 (IN)
TLV_INN: D9.3 (COM), R51.2, U9.3 (IN-)
VREF: R52.2, R53.1, R54.2, TP23.1 (1_1), U9.1 (IN+)
VTACH: R49.1, R51.1, TP22.1 (1_1), U8.5 (EMIT), U8.10 (IN-)
VTACH_RAW: C35.1, R48.1, U8.3 (CP2), U8.4 (IN+)

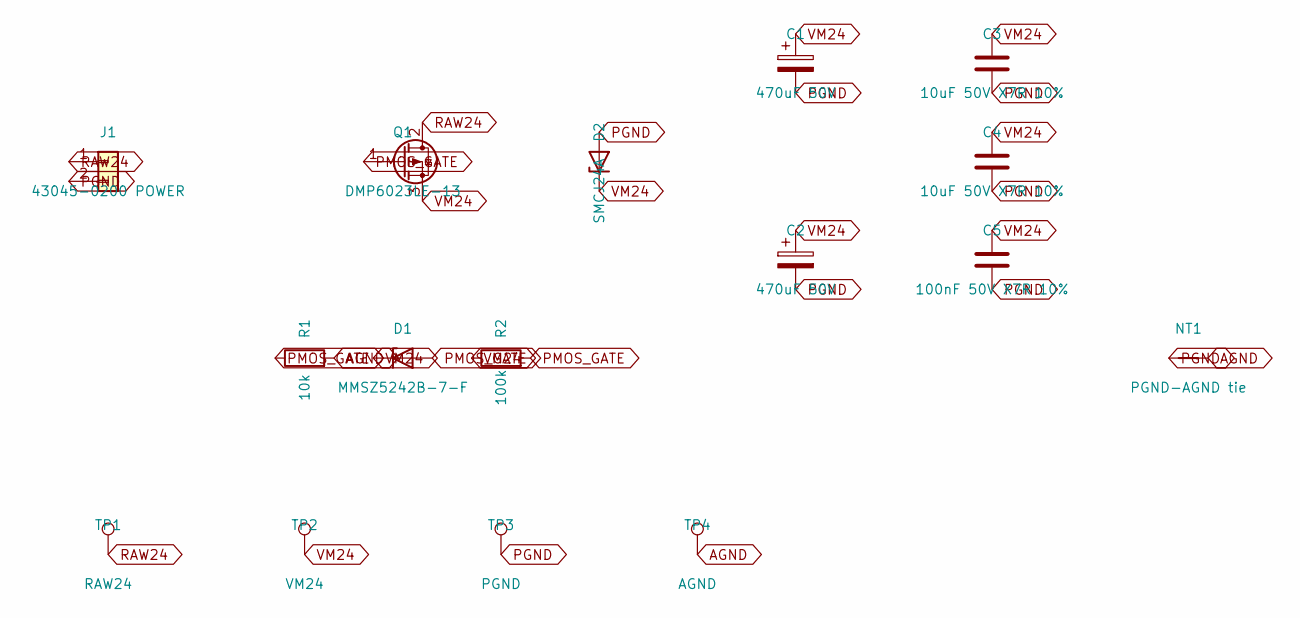
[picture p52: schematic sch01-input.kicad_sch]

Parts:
C1, C2: 470uF 50V; CP_Radial_D10.0mm_P5.00mm; MPN EEU-FR1H471
C3, C4: 10uF 50V X7R 10%; C_1210_3225Metric; LCSC C2918502
C5: 100nF 50V X7R 10%; C_0603_1608Metric; LCSC C14663
D1: MMSZ5242B-7-F; D_SOD-123; MPN MMSZ5242B-7-F; LCSC C500776
D2: SMCJ24A; D_SMC; MPN SMCJ24A; LCSC C135154
J1: 43045-0200 POWER; Molex_Micro-Fit_3.0_43045-0200_2x01_P3.00mm_Horizontal; MPN 43045-0200
NT1: PGND-AGND tie; NetTie-2_SMD_Pad2.0mm
Q1: DMP6023LE-13; SOT-223-3_TabPin2; MPN DMP6023LE-13; LCSC C154901
R1: 10k; R_0402_1005Metric; MPN 0402WGF1002TCE; LCSC C25744
R2: 100k; R_0402_1005Metric; LCSC C25741
TP1: RAW24; TestHole_2.4mm_PTH1.0mm
TP2: VM24; TestHole_2.4mm_PTH1.0mm
TP3: PGND; TestHole_2.4mm_PTH1.0mm
TP4: AGND; TestHole_2.4mm_PTH1.0mm

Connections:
PMOS_GATE: D1.2 (A), Q1.1 (G), R1.1, R2.2
RAW24: J1.1, Q1.2 (D), TP1.1 (1_1)

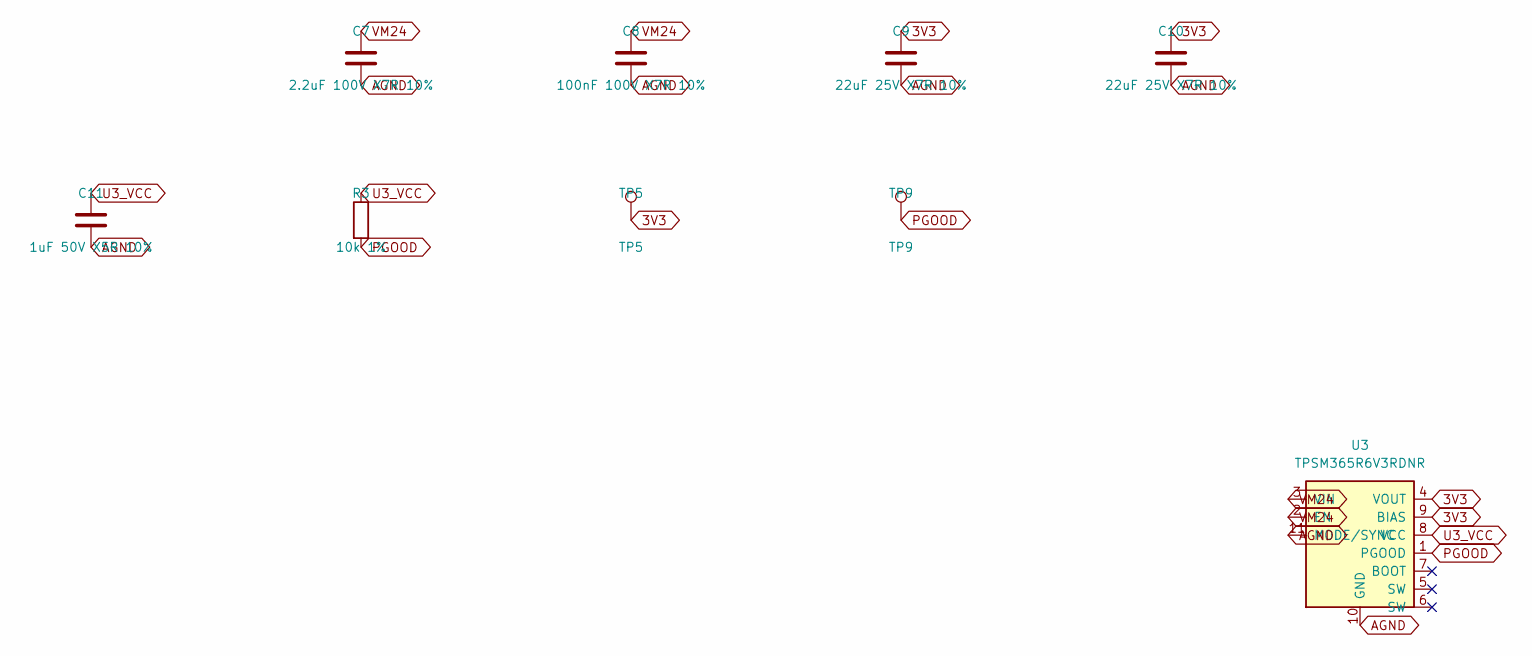
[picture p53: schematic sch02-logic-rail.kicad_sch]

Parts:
C7: 2.2uF 100V X7R 10%; C_1210_3225Metric
C8: 100nF 100V X7R 10%; C_0805_2012Metric
C9, C10: 22uF 25V X7R 10%; C_1210_3225Metric
C11: 1uF 50V X5R 10%; C_0603_1608Metric
R3: 10k 1%; R_0402_1005Metric
TP5: TP5; TestHole_2.4mm_PTH1.0mm
TP9: TP9; TestHole_2.4mm_PTH1.0mm
U3: TPSM365R6V3RDNR; TPSM365R6_RDN0011A

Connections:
3V3: C9.1, C10.1, TP5.1 (1_1), U3.4 (VOUT), U3.9 (BIAS); also elsewhere on the board
PGOOD: R3.2, TP9.1 (1_1), U3.1 (PGOOD); also elsewhere on the board
U3_VCC: C11.1, R3.1, U3.8 (VCC)

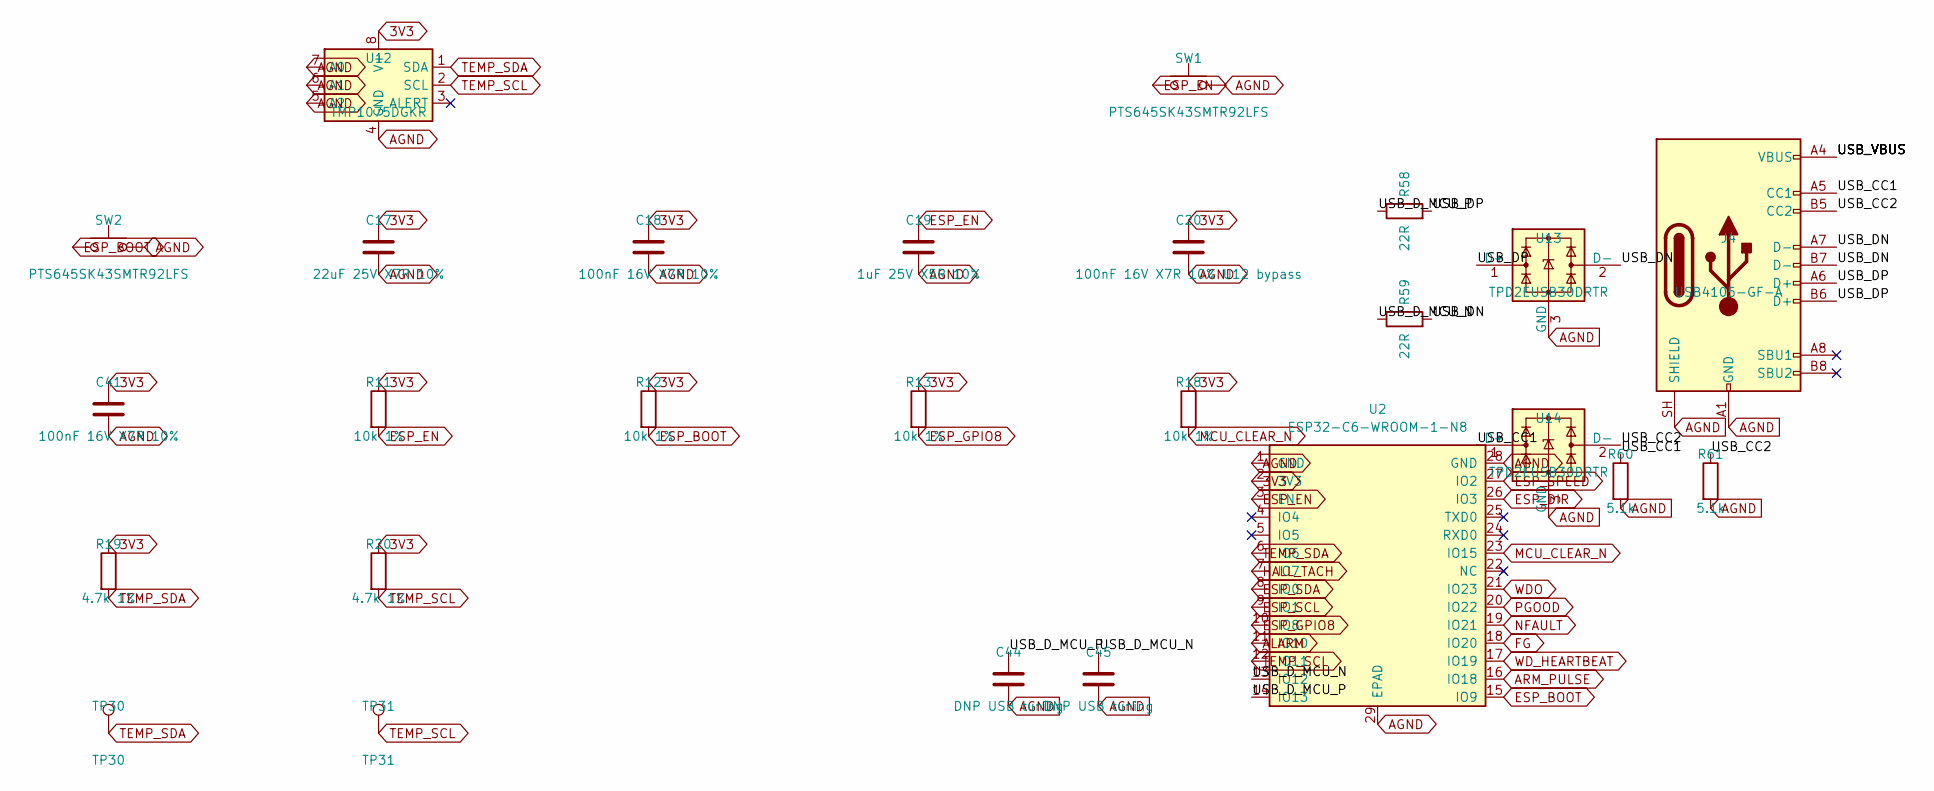
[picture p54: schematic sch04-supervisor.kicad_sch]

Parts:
C17: 22uF 25V X7R 10%; C_1210_3225Metric
C18, C41: 100nF 16V X7R 10%; C_0402_1005Metric
C19: 1uF 25V X5R 10%; C_0402_1005Metric
C20: 100nF 16V X7R 10% U12 bypass; C_0402_1005Metric
C44, C45: DNP USB tuning; C_0402_1005Metric
J4: USB4105-GF-A; USB_C_Receptacle_GCT_USB4105-xx-A_16P_TopMnt_Horizontal; MPN USB4105-GF-A; LCSC C3020560
R11, R12, R13, R18: 10k 1%; R_0402_1005Metric
R19, R20: 4.7k 1%; R_0402_1005Metric
R58, R59: 22R; R_0402_1005Metric; MPN 0402WGF220JTCE; LCSC C25092
R60, R61: 5.1k; R_0402_1005Metric; MPN 0402WGF5101TCE; LCSC C25905
SW1, SW2: PTS645SK43SMTR92LFS; SW_SPST_PTS645Sx43SMTR92
TP30: TP30; TestHole_2.4mm_PTH1.0mm
TP31: TP31; TestHole_2.4mm_PTH1.0mm
U2: ESP32-C6-WROOM-1-N8; ESP32-C6-WROOM-1
U12: TMP1075DGKR; VSSOP-8_3x3mm_P0.65mm_Clearance0.20
U13, U14: TPD2EUSB30DRTR; Texas_DRT-3; MPN TPD2EUSB30DRTR; LCSC C97502

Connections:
3V3: C17.1, C18.1, C20.1, C41.1, R11.1, R12.1, R13.1, R18.1, R19.1, R20.1, U2.2 (3V3), U12.8 (V+); also elsewhere on the board
/SCH-04 Supervisor + Service/USB_CC1: J4.A5 (CC1), R60.1, U14.1 (D+)
/SCH-04 Supervisor + Service/USB_CC2: J4.B5 (CC2), R61.1, U14.2 (D-)
/SCH-04 Supervisor + Service/USB_DN: J4.A7 (D-), J4.B7 (D-), R59.2, U13.2 (D-)
/SCH-04 Supervisor + Service/USB_DP: J4.A6 (D+), J4.B6 (D+), R58.2, U13.1 (D+)
/SCH-04 Supervisor + Service/USB_D_MCU_N: C45.1, R59.1, U2.13 (IO12)
/SCH-04 Supervisor + Service/USB_D_MCU_P: C44.1, R58.1, U2.14 (IO13)
/SCH-04 Supervisor + Service/USB_VBUS: J4.A4 (VBUS), J4.A9 (VBUS), J4.B4 (VBUS), J4.B9 (VBUS)
ALARM: U2.11 (IO10); also elsewhere on the board
ARM_PULSE: U2.16 (IO18); also elsewhere on the board
ESP_BOOT: R12.2, SW2.1, U2.15 (IO9)
ESP_DIR: U2.26 (IO3); also elsewhere on the board
ESP_EN: C19.1, R11.2, SW1.1, U2.3 (EN)
ESP_GPIO8: R13.2, U2.10 (IO8)
ESP_SCL: U2.9 (IO1); also elsewhere on the board
ESP_SDA: U2.8 (IO0); also elsewhere on the board
ESP_SPEED: U2.27 (IO2); also elsewhere on the board
FG: U2.18 (IO20); also elsewhere on the board
HALL_TACH: U2.7 (IO7); also elsewhere on the board
MCU_CLEAR_N: R18.2, U2.23 (IO15); also elsewhere on the board
NFAULT: U2.19 (IO21); also elsewhere on the board
PGOOD: U2.20 (IO22); also elsewhere on the board
TEMP_SCL: R20.2, TP31.1 (1_1), U2.12 (IO11), U12.2 (SCL)
TEMP_SDA: R19.2, TP30.1 (1_1), U2.6 (IO6), U12.1 (SDA)
WDO: U2.21 (IO23); also elsewhere on the board
WD_HEARTBEAT: U2.17 (IO19); also elsewhere on the board

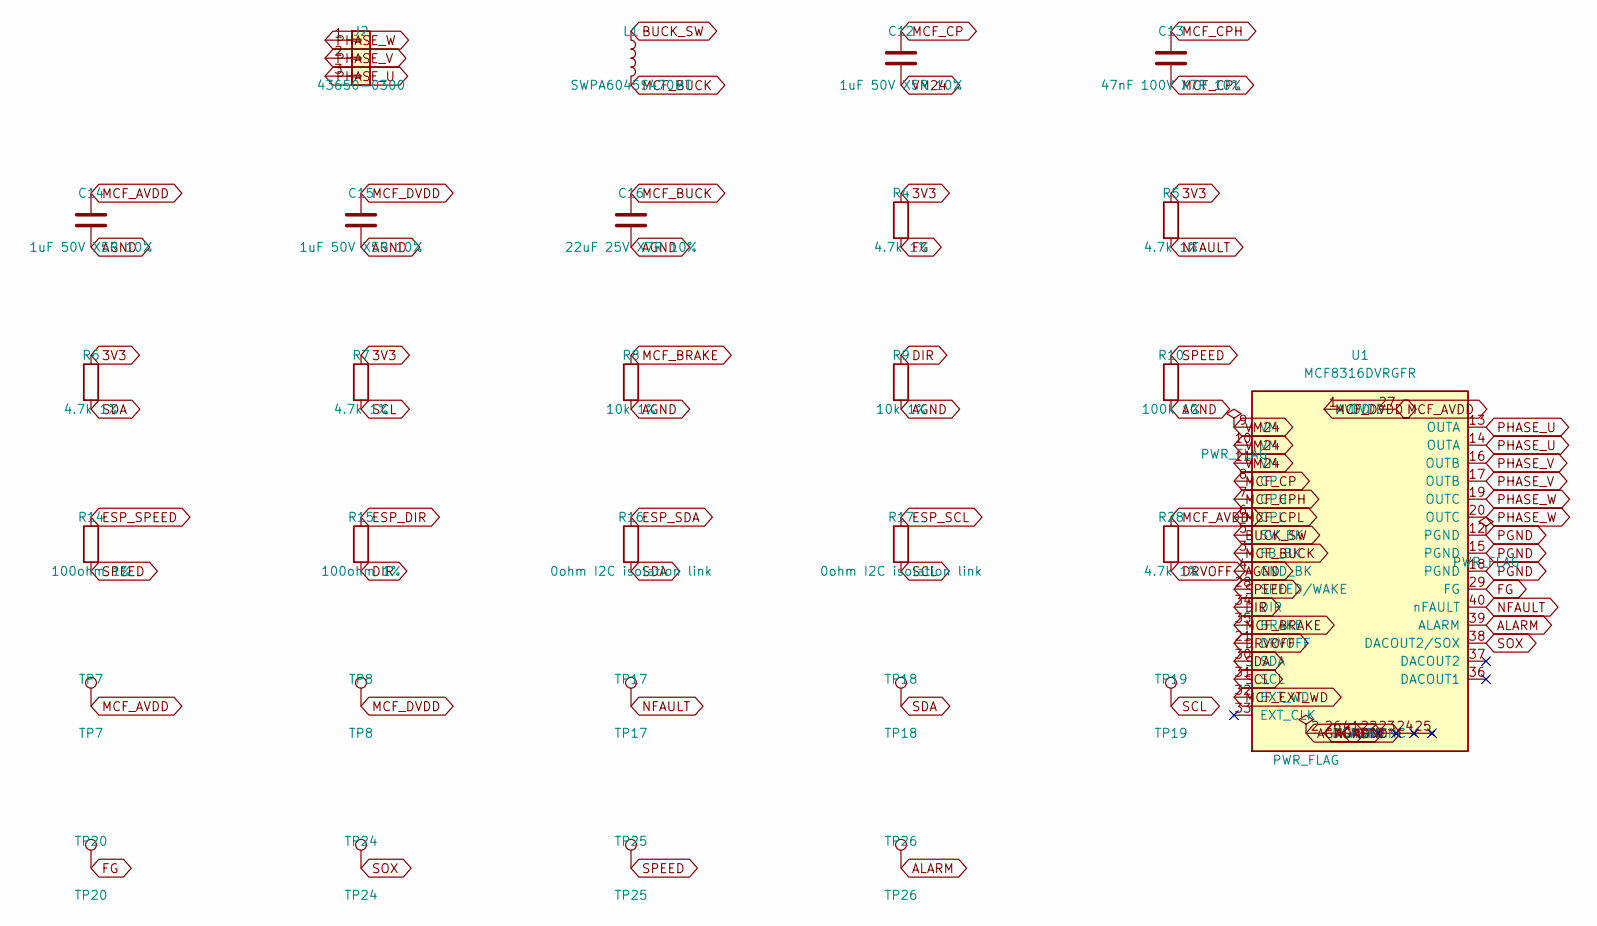
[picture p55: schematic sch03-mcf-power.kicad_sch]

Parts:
C12, C14, C15: 1uF 50V X5R 10%; C_0603_1608Metric
C13: 47nF 100V X7R 10%; C_0805_2012Metric
C16: 22uF 25V X7R 10%; C_1210_3225Metric
J2: 43650-0300; Molex_Micro-Fit_3.0_43650-0300_1x03_P3.00mm_Horizontal
L1: SWPA6045S470MT; L_Sunlord_SWPA6045S
R4, R5, R6, R7, R28: 4.7k 1%; R_0402_1005Metric
R8, R9: 10k 1%; R_0402_1005Metric
R10: 100k 1%; R_0402_1005Metric
R14, R15: 100ohm 1%; R_0402_1005Metric
R16, R17: 0ohm I2C isolation link; R_0402_1005Metric
TP7: TP7; TestHole_2.4mm_PTH1.0mm
TP8: TP8; TestHole_2.4mm_PTH1.0mm
TP17: TP17; TestHole_2.4mm_PTH1.0mm
TP18: TP18; TestHole_2.4mm_PTH1.0mm
TP19: TP19; TestHole_2.4mm_PTH1.0mm
TP20: TP20; TestHole_2.4mm_PTH1.0mm
TP24: TP24; TestHole_2.4mm_PTH1.0mm
TP25: TP25; TestHole_2.4mm_PTH1.0mm
TP26: TP26; TestHole_2.4mm_PTH1.0mm
U1: MCF8316DVRGFR; MCF8316D_RGF0040E

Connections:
3V3: R4.1, R5.1, R6.1, R7.1; also elsewhere on the board
ALARM: TP26.1 (1_1), U1.39 (ALARM); also elsewhere on the board
BUCK_SW: L1.1, U1.5 (SW_BK)
DIR: R9.1, R15.2, U1.34 (DIR)
DRVOFF: R28.2, U1.21 (DRVOFF); also elsewhere on the board
ESP_DIR: R15.1; also elsewhere on the board
ESP_SCL: R17.1; also elsewhere on the board
ESP_SDA: R16.1; also elsewhere on the board
ESP_SPEED: R14.1; also elsewhere on the board
FG: R4.2, TP20.1 (1_1), U1.29 (FG); also elsewhere on the board
MCF_AVDD: C14.1, R28.1, TP7.1 (1_1), U1.27 (AVDD)
MCF_BRAKE: R8.1, U1.35 (BRAKE)
MCF_BUCK: C16.1, L1.2, U1.3 (FB_BK)
MCF_CP: C12.1, U1.8 (CP)
MCF_CPH: C13.1, U1.7 (CPH)
MCF_CPL: C13.2, U1.6 (CPL)
MCF_DVDD: C15.1, TP8.1 (1_1), U1.1 (DVDD)
MCF_EXT_WD: U1.32 (EXT_WD); also elsewhere on the board
NFAULT: R5.2, TP17.1 (1_1), U1.40 (nFAULT); also elsewhere on the board
PHASE_U: J2.3, U1.13 (OUTA), U1.14 (OUTA)
PHASE_V: J2.2, U1.16 (OUTB), U1.17 (OUTB)
PHASE_W: J2.1, U1.19 (OUTC), U1.20 (OUTC)
SCL: R7.2, R17.2, TP19.1 (1_1), U1.31 (SCL)
SDA: R6.2, R16.2, TP18.1 (1_1), U1.30 (SDA)
SOX: TP24.1 (1_1), U1.38 (DACOUT2/SOX)
SPEED: R10.1, R14.2, TP25.1 (1_1), U1.28 (SPEED/WAKE)

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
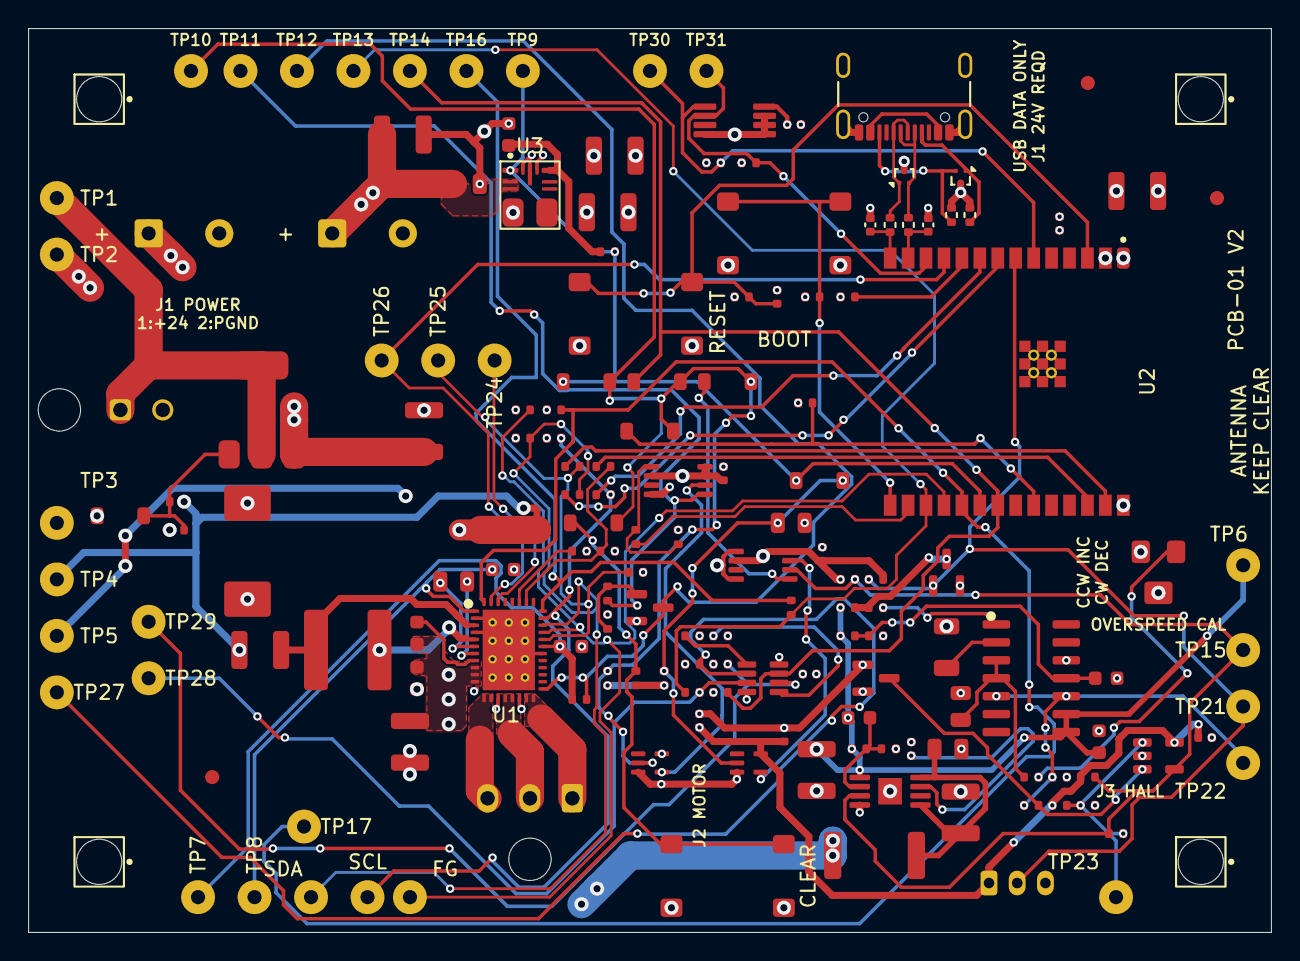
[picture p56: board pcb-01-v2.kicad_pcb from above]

Board: 4 copper layers, 88.0 x 64.0 mm, 166 parts (0 on the bottom side), 78 nets.

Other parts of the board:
FID1, FID2, FID3: FIDUCIAL; Fiducial_1mm_Mask2mm
H1, H2, H3, H4: M3 NPTH; MountingHole_M3_3.2mm

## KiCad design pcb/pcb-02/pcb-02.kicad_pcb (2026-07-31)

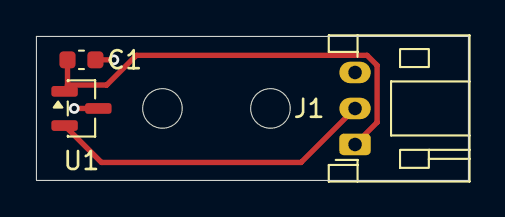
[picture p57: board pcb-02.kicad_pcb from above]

Board: 2 copper layers, 24.0 x 8.0 mm, 5 parts (0 on the bottom side), 3 nets.

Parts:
C1: 100nF; C_0603_1608Metric
H1, H2: MountingHole; MountingHole_2.2mm_M2
J1: HALL_TO_J3; JST_PH_S3B-PH-K_1x03_P2.00mm_Horizontal
U1: DRV5033FAQDBZR; SOT-23

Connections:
/3V3: C1.1, J1.1, U1.1 (VCC)
/AGND: C1.2, J1.3, U1.3 (GND)
/HALL_TACH: J1.2, U1.2 (OUT)

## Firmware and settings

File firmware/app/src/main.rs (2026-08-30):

//! Stillair ceiling-fan supervisor firmware.
//!
//! Runs on the ESP32-C6-WROOM-1-N8 on the custom PCB-01 V2 controller board.
//! The supervisor configures the MCF8316D over I²C and commands speed/direction;
//! it never switches motor phases. The behavioral contract lives in `docs/controls.md`
//! and is implemented — and unit-tested on the host — in `stillair-core`; this crate is
//! only the wiring that turns that contract into GPIO edges.
//!
//! GPIO map (verified against the ESP32-C6-WROOM-1 datasheet; GPIO15 is the only strap
//! pin used — its JTAG-select strap is ignored with default eFuses and the external
//! pull-up satisfies its no-float requirement):
//!
//! | GPIO    | Signal                       |
//! |---------|------------------------------|
//! | 0 / 1   | SDA / SCL (MCF I²C)          |
//! | 2       | SPEED PWM                    |
//! | 3       | DIR                          |
//! | 6       | TEMP_SDA                     |
//! | 7       | HALL_TACH sense (plausibility check input) |
//! | 10      | MCF ALARM (active-high)      |
//! | 11      | TEMP_SCL                     |
//! | 12 / 13 | USB D− / D+                  |
//! | 15      | MCU_CLEAR_N (open-drain out) |
//! | 16 / 17 | NC                           |
//! | 18      | permission ARM_PULSE         |
//! | 19      | watchdog heartbeat           |
//! | 20      | MCF FG                       |
//! | 21      | MCF nFAULT                   |
//! | 22      | 3.3 V PGOOD                  |
//! | 23      | watchdog WDO diagnostic      |

#![no_std]
#![no_main]

use core::sync::atomic::{AtomicBool, AtomicU32, Ordering};

use embassy_time::{Duration, Instant, Timer};
use esp_backtrace as _;
use esp_hal::gpio::{DriveMode, Input, InputConfig, Level, Output, OutputConfig, Pull};
use esp_hal::interrupt::Priority;
use esp_hal::ledc::channel::ChannelIFace;
use esp_hal::ledc::timer::TimerIFace;
use esp_hal::ledc::{channel, timer, LSGlobalClkSource, Ledc, LowSpeed};
use esp_hal::time::Rate;
use esp_hal::timer::timg::TimerGroup;
use esp_hal::usb::usb_serial_jtag::UsbSerialJtag;
use esp_rtos::embassy::InterruptExecutor;
use static_cell::StaticCell;
use stillair_core::config;
use stillair_core::console::Telemetry;
use stillair_core::mcf8316::{self, reg};
use stillair_core::mcf_config::{self, ConfigCheck, ConfigFault};
use stillair_core::speed;
use stillair_core::state::{Command, FanState, Inputs, StatusRead, Supervisor};
use stillair_core::time::Millis;

mod board;
mod console;
mod matter;
mod mcf;
mod output;
mod wifi_diag;

use board::{
    Board, FG_PULSES, HALL_LAST_EDGE_MS, HALL_PERIOD_MS, HALL_PULSES, PGOOD_FELL, PGOOD_HIGH,
};
use mcf::{service_access, Mcf};

esp_bootloader_esp_idf::esp_app_desc!();

/// Control-loop cadence. Fast enough that the ramp is smooth and a fault is acted on
/// promptly, slow enough to be nowhere near the watchdog's 1.6 s window.
const CONTROL_TICK: Duration = Duration::from_millis(50);

/// Incremented by the control loop on every completed poll. The heartbeat task refuses to
/// toggle unless this has advanced, which is what makes the watchdog attest control-loop
/// liveness rather than merely CPU liveness (`docs/controls.md` > "Firmware safety
/// architecture").
static CONTROL_LOOP_BEAT: AtomicU32 = AtomicU32::new(0);

/// True only while main holds MCU_CLEAR_N asserted during hardware initialization.
///
/// The MCF's stored external watchdog can already be active when it wakes, so its shared
/// heartbeat pin must toggle during a slow address sweep. This flag permits that boot-only
/// service while drive is independently impossible. Once the real control task exists, the
/// heartbeat again advances only when [`CONTROL_LOOP_BEAT`] does.
static BOOT_INHIBIT_ACTIVE: AtomicBool = AtomicBool::new(true);

static LEDC: StaticCell<Ledc<'static>> = StaticCell::new();
static SPEED_TIMER: StaticCell<timer::Timer<'static, LowSpeed>> = StaticCell::new();

/// The control loop, the heartbeat, and the tach counters run here, above everything else.
///
/// This split is structural rather than a convention to remember. Once the Matter/Wi-Fi
/// tasks exist on the thread-mode executor, a hung network stack must degrade to the
/// network-loss row of the failure table (the fan keeps its speed) — not starve the
/// heartbeat and trip the watchdog, which would stop the fan. Establishing the higher
/// priority *before* those tasks exist is the only way that stays true by construction.
static CONTROL_EXECUTOR: StaticCell<InterruptExecutor<1>> = StaticCell::new();

/// MCF register service runs above Matter/Wi-Fi but below the safety-critical control loop.
///
/// A commissioned Matter stack can keep the thread-mode executor busy for longer than the
/// supervisor's status-freshness deadline. Giving the bounded software-I2C task its own middle
/// priority prevents network work from looking like a dead motor-controller bus, while Priority3
/// control and watchdog work can still preempt every register transaction.
static MCF_EXECUTOR: StaticCell<InterruptExecutor<2>> = StaticCell::new();

#[esp_rtos::main]
async fn main(spawner: embassy_executor::Spawner) {
    // Not `esp_println::logger`: every line, log or protocol, goes through one queue and
    // one async writer. See `output.rs` for why printing from a critical section is not an
    // option once telemetry streams.
    output::init(log::LevelFilter::Info);

    let peripherals = esp_hal::init(esp_hal::Config::default());

    // Sized for Wi-Fi + BLE coexistence plus the ~4 KB of x509 work rs-matter's attestation
    // path allocates. The supervisor itself allocates nothing — everything on the control
    // path is statically sized — so this whole heap belongs to the radio and Matter.
    esp_alloc::heap_allocator!(size: 100 * 1024);

    let timg0 = TimerGroup::new(peripherals.TIMG0);
    let sw_int =
        esp_hal::interrupt::software::SoftwareInterruptControl::new(peripherals.SW_INTERRUPT);
    esp_rtos::start(timg0.timer0, sw_int.software_interrupt0);

    log::info!("stillair supervisor boot");

    // Outputs. Every one powers up in its safe state: no direction change, no permission
    // request, and permission actively revocable.
    let push_pull = OutputConfig::default();
    let open_drain = OutputConfig::default().with_drive_mode(DriveMode::OpenDrain);

    let dir = Output::new(peripherals.GPIO3, Level::Low, push_pull);
    let arm = Output::new(peripherals.GPIO18, Level::Low, push_pull);
    // Start asserted. This matters on an ESP-only reset: the external latch can retain an
    // earlier permission state while the MCU reboots. Open-drain means firmware can only
    // revoke permission, never force it on. Safe boot releases the line only after SPEED is
    // confirmed back at zero following the MCF wake/recovery sequence.
    let mut clear_n = Output::new(peripherals.GPIO15, Level::Low, open_drain);
    let heartbeat = Output::new(peripherals.GPIO19, Level::Low, push_pull);

    // Start the heartbeat before probing the MCF. A stored external-watchdog configuration
    // may already be live after SPEED wakes the device, and a changed I2C target can make the
    // bounded address sweep longer than its 1000 ms window. During this early service
    // MCU_CLEAR_N is held low, so heartbeat activity cannot accompany drive permission.
    let control = CONTROL_EXECUTOR
        .init(InterruptExecutor::new(sw_int.software_interrupt1))
        .start(Priority::Priority3);
    control.spawn(heartbeat_task(heartbeat).unwrap());
    let mcf_executor = MCF_EXECUTOR
        .init(InterruptExecutor::new(sw_int.software_interrupt2))
        .start(Priority::Priority2);

    // Inputs. No internal pulls: the board provides them.
    let floating = InputConfig::default().with_pull(Pull::None);
    let pgood = Input::new(peripherals.GPIO22, floating);
    PGOOD_HIGH.store(pgood.is_high(), Ordering::Release);
    let nfault = Input::new(peripherals.GPIO21, floating);
    let alarm = Input::new(peripherals.GPIO10, floating);
    let fg = Input::new(peripherals.GPIO20, floating);
    let hall = Input::new(peripherals.GPIO7, floating);

    // SPEED-pin PWM. 11-bit at 1 kHz, inside the MCF's `SPEED_RANGE_SEL` = 0h band.
    let ledc = LEDC.init(Ledc::new(peripherals.LEDC));
    ledc.set_global_slow_clock(LSGlobalClkSource::APBClk);
    let speed_timer = SPEED_TIMER.init(ledc.timer::<LowSpeed>(timer::Number::Timer0));
    speed_timer
        .configure(timer::config::Config {
            duty: timer::config::Duty::Duty11Bit,
            clock_source: timer::LSClockSource::APBClk,
            frequency: Rate::from_hz(config::SPEED_CARRIER_HZ),
        })
        .expect("SPEED carrier must be configurable at 1 kHz / 11 bit");

    let mut speed = ledc.channel(channel::Number::Channel0, peripherals.GPIO2);
    speed
        .configure(channel::config::Config {
            timer: speed_timer,
            duty_pct: 0,
            drive_mode: DriveMode::PushPull,
        })
        .expect("SPEED channel must configure");

    let mut speed = board::SpeedPwm::new(speed);
    // The MCF8316D requires a 100 us pause after every I2C byte. The ESP packet engine cannot
    // express that timing, so this small dedicated software bus owns GPIO0/1 and inserts the
    // pause exactly while preserving normal-speed data bits and protocol CRC.
    let mut mcf = Mcf::new(
        peripherals.GPIO0,
        peripherals.GPIO1,
        mcf8316::DEFAULT_TARGET_ID,
    );

    // First try the expected target at zero SPEED. A controller already in standby answers
    // here and needs no wake command. If it does not answer, recover a stored sleep mode by
    // holding SPEED high beyond TI's 5 ms maximum wake interval, then sweep in case EEPROM
    // also changed the target address. MCU_CLEAR_N stays asserted throughout, so no phase
    // output can be enabled even though SPEED is temporarily near full scale.
    let mut wake_used = false;
    let target = if mcf.probe_current().await {
        Some(mcf8316::DEFAULT_TARGET_ID)
    } else if speed.hold_wake_for_configuration() {
        wake_used = true;
        Timer::after(Duration::from_millis(config::MCF_WAKE_HOLD_MS)).await;
        mcf.probe().await
    } else {
        None
    };
    match target {
        Some(target) => log::info!("MCF8316D found at I2C target {target:#04x}"),
        None => log::error!("no MCF8316D on the I2C bus; status reads will fail"),
    }
    let standby = match target {
        Some(_) => mcf_config::ensure_standby(&mut mcf).await,
        None => Err(mcf_config::ConfigFault::Unreadable {
            address: mcf8316::reg::DEVICE_CONFIG2,
        }),
    };
    match standby {
        Ok(true) => log::warn!("MCF sleep mode cleared in volatile shadow for commissioning"),
        Ok(false) => log::info!("MCF standby mode already active"),
        Err(error) => log::error!("MCF standby recovery failed: {error:?}"),
    }
    if !speed.idle_after_configuration() {
        // `clear_n` deliberately remains asserted. Starting the supervisor with a stale
        // near-full SPEED command would let a later arm produce an uncontrolled start,
        // because its duty cache correctly assumes hardware began at zero.
        panic!("SPEED could not be returned to zero after MCF wake");
    }

    if wake_used {
        // A high speed command while DRVOFF is asserted can latch the expected start-failed
        // diagnostic. Clear that recovery artifact only after SPEED is confirmed zero. A
        // real standing condition reasserts, and permission remains revoked for the full
        // supervisor safe-boot hold before any user command can arm the drive.
        match mcf.clear_faults().await {
            Ok(()) => Timer::after(Duration::from_millis(250)).await,
            Err(error) => log::error!("failed to clear MCF wake diagnostic: {error:?}"),
        }
    }
    clear_n.set_high();

    let verdict = match standby {
        Ok(_) => mcf_config::check(&mut mcf, mcf_config::IMAGE).await,
        Err(error) => ConfigCheck::Failed(error),
    };
    match verdict {
        ConfigCheck::Verified => log::info!("MCF stored configuration verified"),
        ConfigCheck::Unverified => log::warn!(
            "MCF configuration is not runnable: use `config stage` for volatile bench \
             commissioning, or capture the tuned golden image"
        ),
        ConfigCheck::Provisional => {
            log::warn!("MCF volatile first-spin configuration staged; EEPROM unchanged")
        }
        other => log::error!("MCF stored configuration check failed: {other:?}"),
    }
    mcf::publish_verdict(verdict);

    let board = Board::new(dir, arm, clear_n, speed, nfault, alarm);

    // Everything else that must keep running when the network does not.
    control.spawn(fg_task(fg).unwrap());
    control.spawn(hall_task(hall).unwrap());
    control.spawn(pgood_task(pgood).unwrap());
    control.spawn(control_task(board).unwrap());
    BOOT_INHIBIT_ACTIVE.store(false, Ordering::Release);

    // Status and bounded register service must outlive stalls in Matter/Wi-Fi, but remain
    // preemptible by the Priority3 control and watchdog path.
    mcf_executor.spawn(mcf_task(mcf).unwrap());
    // The tuning console and network stack remain on the thread-mode executor. PCB-01 V2
    // exposes the C6's native USB Serial/JTAG peripheral; GPIO12/13 remain dedicated to it.
    let (console_rx, console_tx) = UsbSerialJtag::new(peripherals.USB_DEVICE)
        .into_async()
        .split();
    spawner.spawn(output::writer_task(console_tx).unwrap());
    spawner.spawn(console::console_task(console_rx).unwrap());
    spawner.spawn(console::stream_task().unwrap());
    spawner.spawn(wifi_diag::sample_task().unwrap());

    // Matter runs to the end of `main`, which *is* the thread-mode executor's own task —
    // below the control loop's Priority3 interrupt executor by construction. Everything the
    // fan needs to stay safe has already been spawned above and keeps running regardless of
    // what the network stack does, which is the network-loss row of the failure table.
    matter::run(
        peripherals.RNG,
        peripherals.ADC1,
        peripherals.WIFI,
        peripherals.BT,
        peripherals.FLASH,
    )
    .await;
}

/// Drives the fan state machine. All the decisions live in `stillair-core`; this loop only
/// samples pins, hands time and inputs in, and applies whatever comes back.
#[embassy_executor::task]
async fn control_task(mut board: Board) {
    let initial = board.inputs();
    let mut supervisor = Supervisor::new(now(), &initial);
    let mut reported = supervisor.state();

    loop {
        let config_service = console::config_service_active();
        while let Ok(command) = console::COMMANDS.try_receive() {
            if !config_service {
                supervisor.command(command);
            }
        }
        if config_service && supervisor.state() != FanState::Fault {
            supervisor.command(Command::Off);
        }
        if console::take_mpet_abort() {
            supervisor.command(Command::AbortMpet);
        }

        let mut inputs: Inputs = board.inputs();
        // The MCF shadow registers disappear with its rail even if USB keeps the ESP alive.
        // Invalidate both provisional and stored verdicts on the falling edge. A provisional
        // image must be staged again; a stored image must be checked again after power returns.
        let pgood_fell = PGOOD_FELL.swap(false, Ordering::AcqRel);
        if pgood_fell {
            mcf::invalidate_current_profile_readiness();
        }
        let verdict = mcf_config::after_pgood_loss(pgood_fell, mcf::verdict());
        if verdict != mcf::verdict() {
            mcf::publish_verdict(verdict);
        }
        // Absent a fresh read this stays `Stale`, which the supervisor treats as carrying
        // no information — neither evidence of a fault nor evidence of health.
        inputs.mcf_status = mcf::STATUS.try_take().unwrap_or(StatusRead::Stale);
        // A level, not an event: the last verdict stands until something changes it.
        inputs.config = mcf::verdict();

        for action in supervisor.poll(now(), &inputs) {
            board.apply(action);
        }

        if supervisor.state() != reported {
            reported = supervisor.state();
            log::info!(
                "state {:?} cmd {} rpm measured {} rpm fault {:?}",
                reported,
                supervisor.commanded().whole_rpm(),
                supervisor.measured().whole_rpm(),
                supervisor.fault()
            );
        }

        console::publish(Telemetry {
            uptime_ms: now().0,
            state: supervisor.state(),
            fault: supervisor.fault(),
            on: supervisor.commanded_on(),
            target: supervisor.target(),
            commanded: supervisor.commanded(),
            measured_fg: supervisor.measured(),
            measured_hall: supervisor.measured_hall(),
            duty: speed::duty_for(supervisor.commanded()),
            direction: supervisor.direction(),
            requested_direction: supervisor.requested_direction(),
            released_min: supervisor.released_min(),
            config: supervisor.config(),
            dropped: output::dropped(),
        });

        CONTROL_LOOP_BEAT.fetch_add(1, Ordering::Relaxed);
        Timer::after(CONTROL_TICK).await;
    }
}

/// Tracks the MCF rail independently of the 50 ms control-loop sampling cadence.
#[embassy_executor::task]
async fn pgood_task(mut pgood: Input<'static>) {
    // Close the startup gap between the initial sample and this task beginning to await
    // edges. If the rail fell during that interval, preserve it as a falling event.
    let high = pgood.is_high();
    if PGOOD_HIGH.swap(high, Ordering::AcqRel) && !high {
        PGOOD_FELL.store(true, Ordering::Release);
    }
    loop {
        pgood.wait_for_any_edge().await;
        let high = pgood.is_high();
        PGOOD_HIGH.store(high, Ordering::Release);
        if !high {
            PGOOD_FELL.store(true, Ordering::Release);
        }
    }
}

/// Services the TPS3435 watchdog (2 Hz square wave on GPIO19).
///
/// Deliberately bit-banged, and deliberately conditional: a free-running peripheral would
/// keep feeding the watchdog straight through a hung control loop, which is exactly the
/// failure the watchdog exists to catch. If the control loop stops advancing its beat, the
/// toggling stops, the TPS3435 pulses WDO, and the hardware latch revokes drive permission
/// without firmware's involvement.
#[embassy_executor::task]
async fn heartbeat_task(mut heartbeat: Output<'static>) {
    let half_period = Duration::from_hz(u64::from(config::WATCHDOG_HEARTBEAT_HZ) * 2);
    let mut last_beat = CONTROL_LOOP_BEAT.load(Ordering::Relaxed);

    loop {
        Timer::after(half_period).await;
        if BOOT_INHIBIT_ACTIVE.load(Ordering::Acquire) {
            heartbeat.toggle();
            continue;
        }
        let beat = CONTROL_LOOP_BEAT.load(Ordering::Relaxed);
        if beat == last_beat {
            // Say nothing, do nothing: letting the watchdog time out *is* the response.
            continue;
        }
        last_beat = beat;
        heartbeat.toggle();
    }
}

/// Polls the MCF's fault-status registers and services fault-clear requests.
///
/// Deliberately on the middle-priority executor: I²C is slow and can hang, so Priority3 control
/// and watchdog work must always preempt it. Keeping it above thread-mode Matter/Wi-Fi prevents
/// network work from starving status freshness. A bus that stops answering shows up to the
/// supervisor as accumulating `BusError`s, which becomes a stop after
/// [`config::BUS_FAILURES_BEFORE_FAULT`] — the drive is not commanded by something that can
/// no longer interrogate it.
async fn service_digital_speed_override(
    mcf_device: &mut Mcf,
    last_digital_speed: &mut Option<u32>,
    digital_speed_healthy: &mut bool,
) {
    match mcf::service_digital_speed(mcf_device, last_digital_speed).await {
        Ok(()) if !*digital_speed_healthy => {
            log::info!("MCF digital speed writes recovered");
            *digital_speed_healthy = true;
        }
        Ok(()) => {}
        Err(error) if *digital_speed_healthy => {
            log::warn!("MCF digital speed write failed: {error:?}");
            *digital_speed_healthy = false;
            mcf::invalidate_current_profile_readiness();
            let fault = match error {
                mcf::BusError::ReadbackMismatch => ConfigFault::Mismatch {
                    address: reg::ALGO_DEBUG1,
                },
                _ => ConfigFault::Unreadable {
                    address: reg::ALGO_DEBUG1,
                },
            };
            mcf::publish_verdict(ConfigCheck::Failed(fault));
        }
        Err(_) => {
            mcf::invalidate_current_profile_readiness();
        }
    }
}
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

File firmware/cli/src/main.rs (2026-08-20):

//! `stillair` — the host end of the tuning harness.
//!
//! Drives a supervisor over the console protocol, against either a real board (`--port`) or
//! the simulator (`--sim`). Everything it prints is machine-readable and it exits non-zero
//! on failure, so a tuning or commissioning step is a shell command with an exit code rather
//! than a person reading a serial log.
//!
//! ```text
//! stillair --sim state
//! stillair --port /dev/tty.usbmodem1101 run 60
//! stillair --port /dev/tty.usbmodem1101 wait running --for 30
//! stillair --sim stream 10 --for 120 > sweep.csv
//! stillair --sim reg read VM_VOLTAGE
//! ```

use std::io::Write;
use std::process::ExitCode;
use std::time::Duration;

use stillair_core::config;
use stillair_core::console;
use stillair_core::mcf8316::{max_speed_to_milli_rpm, reg, seeds};

mod link;
mod sim;

use link::{field, Link, SerialLink};
use sim::Simulator;

/// How long to wait for a reply to a command before calling the link dead.
const REPLY_TIMEOUT: Duration = Duration::from_secs(2);

fn main() -> ExitCode {
    let arguments: Vec<String> = std::env::args().skip(1).collect();
    match run(&arguments) {
        Ok(()) => ExitCode::SUCCESS,
        // Piping into `head` is ordinary usage, not a failure of the run.
        Err(message) if message.contains("Broken pipe") => ExitCode::SUCCESS,
        Err(message) => {
            eprintln!("stillair: {message}");
            ExitCode::FAILURE
        }
    }
}

fn run(arguments: &[String]) -> Result<(), String> {
    let mut arguments = arguments.iter().map(String::as_str).peekable();
    let mut link: Option<Box<dyn Link>> = None;

    while let Some(argument) = arguments.peek() {
        match *argument {
            "--sim" => {
                arguments.next();
                link = Some(Box::new(Simulator::new()));
            }
            "--port" => {
                arguments.next();
                let path = arguments.next().ok_or("--port needs a device path")?;
                link = Some(Box::new(
                    SerialLink::open(path).map_err(|error| error.to_string())?,
                ));
            }
            "--help" | "-h" => {
                usage();
                return Ok(());
            }
            _ => break,
        }
    }

    let rest: Vec<&str> = arguments.collect();
    if rest.is_empty() {
        usage();
        return Err("no command given".into());
    }
    let mut link = link.ok_or("choose a target: --sim or --port <device>")?;

    if rest[0] == "script" {
        return script(link.as_mut(), rest.get(1).copied().unwrap_or("-"));
    }
    step(link.as_mut(), &rest)
}

/// Consume anything already queued on the link.
///
/// Without this, a reply left behind by a previous step — the `stream off` ack that `wait`
/// sends on its way out, say — is picked up as the answer to the *next* command, and every
/// reply in a script shifts by one. That misattribution is worse than a missing reply: the
/// script keeps running and reports the wrong register's value as the right one.
fn drain(link: &mut dyn Link) {
    while let Ok(Some(_)) = link.receive(Duration::from_millis(20)) {}
}

/// Run one step: a host command, or anything else passed through to the device.
fn step(link: &mut dyn Link, words: &[&str]) -> Result<(), String> {
    drain(link);
    match words[0] {
        "dwell" => dwell(link, &words[1..]),
        "wait" if words.get(1) == Some(&"speed") => wait_speed(link, &words[2..]),
        "wait" => wait(link, &words[1..]),
        // `stream on 10` / `stream off` are the device's own syntax and must reach it; the
        // host verb is `stream <hz>`, distinguished by its argument being a number.
        "stream" if !matches!(words.get(1), Some(&"on") | Some(&"off")) => {
            stream(link, &words[1..])
        }
        "speed" if words.get(1) == Some(&"sample") => sample_speed(link, &words[2..]),
        "estimator" if words.get(1) == Some(&"sample") => sample_estimator(link, &words[2..]),
        // `config capture` is a host verb, and `config dump` needs host-side collection
        // because it is the one device command whose reply is many lines rather than one.
        // `config check`, `config stage`, and `config apply` are single-reply and pass
        // straight through.
        "config" if words.get(1) == Some(&"capture") => capture(link),
        "config" if words.get(1) == Some(&"dump") => dump(link),
        "mpet" if words.get(1) == Some(&"run") => mpet_run(link, &words[2..]),
        // Everything else goes to the device verbatim, so the CLI never has to grow a case
        // for a console command it does not need to interpret.
        _ => passthrough(link, &words.join(" ")),
    }
}

/// Run a sequence of steps against **one** session.
///
/// This is what makes the harness usable for anything beyond a single command. Each
/// invocation of the CLI otherwise opens a fresh link — and against `--sim`, a fresh link is
/// a fresh simulator that has forgotten everything, so a two-command sequence would silently
/// test nothing. Commissioning steps are sequences by nature: boot, arm, run, wait, measure.
///
/// Lines are the same commands accepted on the command line. `#` comments and blank lines
/// are ignored. A failing step stops the run and fails, unless prefixed with `-`.
fn script(link: &mut dyn Link, path: &str) -> Result<(), String> {
    let source = if path == "-" {
        std::io::read_to_string(std::io::stdin()).map_err(|error| error.to_string())?
    } else {
        std::fs::read_to_string(path).map_err(|error| format!("{path}: {error}"))?
    };

    let started = link.elapsed();
    for (number, raw) in source.lines().enumerate() {
        let line = raw.split('#').next().unwrap_or("").trim();
        if line.is_empty() {
            continue;
        }
        let (line, optional) = match line.strip_prefix('-') {
            Some(rest) => (rest.trim(), true),
            None => (line, false),
        };
        let words: Vec<&str> = line.split_whitespace().collect();
        if words.is_empty() {
            continue;
        }

        eprintln!(
            "# t={:.3}s {line}",
            (link.elapsed() - started).as_secs_f64()
        );
        match step(link, &words) {
            Ok(()) => {}
            Err(error) if optional => eprintln!("# (ignored) {error}"),
            Err(error) => return Err(format!("line {}: {line}: {error}", number + 1)),
        }
    }
    Ok(())
}
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

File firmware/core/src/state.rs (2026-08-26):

//! The fan supervisor state machine.
//!
//! Sans-I/O by construction: [`Supervisor::poll`] takes the current time and a snapshot of
//! the input pins, and returns the [`Action`]s the caller should apply. It never sleeps,
//! never touches a peripheral, and never reads a clock of its own, so every clause of
//! `docs/controls.md` > "Required state behavior" and "Failure behavior" is exercisable in
//! a unit test — including the ten-second holds, which cost a test nothing.
//!
//! Two invariants are structural rather than incidental, and must survive any refactor:
//! firmware never drives DRVOFF (it can only *request* permission with [`Action::ArmPulse`]
//! and *revoke* it with [`Action::ClearPermission`]), and every permission-clearing event
//! routes back through [`FanState::SafeBoot`] so the TI ten-second hold is paid again.

use heapless::Vec;

use crate::config;
use crate::mcf8316::{FaultStatus, McfCondition};
use crate::mcf_config::{ConfigCheck, ConfigFault};
use crate::speed::{self, MilliRpm, Ramp, SpeedDuty};
use crate::tach::Tach;
use crate::time::Millis;

/// Rotation direction. Changes only while verified stopped.
#[derive(Debug, Clone, Copy, PartialEq, Eq)]
pub enum Direction {
    Forward,
    Reverse,
}

/// Top-level supervisor states, one per contract clause.
#[derive(Debug, Clone, Copy, PartialEq, Eq)]
pub enum FanState {
    /// Hold DRVOFF high for at least `config::SAFE_BOOT_HOLD_SECS` while rails,
    /// watchdog, limits, and stored MCF configuration are verified.
    SafeBoot,
    /// Output disabled, speed command zero.
    IdleOff,
    /// Direction set while stopped, permission armed, DRVOFF released, slow ramp.
    Starting,
    /// Maintain the last local speed even if the Matter controller/Wi-Fi disappears.
    Running,
    /// Permission is armed and settling before the MPET command is issued.
    MpetArming,
    /// Motor-parameter extraction service mode. SPEED stays at zero; the MCF owns the
    /// measurement motion while the normal fault chain and permission latch remain active.
    Mpet,
    /// Ramp to zero and coast (never brake into the supply).
    Stopping,
    /// Ramp to zero, verify near-zero FG, coast, flip DIR, then restart.
    Reversing,
    /// Hi-Z, permission cleared where applicable, diagnostics exposed; a fresh
    /// user command is required to leave.
    Fault,
}

/// Why the supervisor faulted. Reported, never acted on differently — every fault has the
/// same response (permission revoked, speed zero, fresh command required).
#[derive(Debug, Clone, Copy, PartialEq, Eq)]
pub enum FaultReason {
    /// nFAULT asserted but the status registers have not been read (or could not be), so
    /// the cause is unknown. Once a status read lands, [`FaultReason::Mcf`] names it.
    McfFault,
    /// ALARM asserted with no decoded status behind it.
    McfAlarm,
    /// A decoded MCF fault-status condition — undervoltage, thermal, lock, and so on.
    Mcf(McfCondition),
    /// The MCF has been unreachable over I²C for [`config::BUS_FAILURES_BEFORE_FAULT`]
    /// consecutive attempts. Bus recovery is the caller's job; the supervisor's job is to
    /// stop trusting a drive it can no longer interrogate.
    BusUnreachable,
    /// 3.3 V PGOOD dropped while running.
    RailLoss,
    /// FG says the rotor is turning while the Hall channel is silent — the Hall pickup,
    /// magnet, or cable has failed and the analog overspeed chain is blind.
    HallImplausible,
    /// Commanded a start but the rotor never moved: permission never took, the rotor is
    /// jammed, or the analog safety lock is latched (which only a power cycle clears).
    NoRotation,
    /// The rotor would not go quiet, so the start could never be armed.
    NeverStopped,
    /// The host disappeared or extraction did not complete before the device-side limit.
    MpetTimedOut,
    /// The MCF's stored configuration is not the one this firmware is qualified against —
    /// or the device says its own EEPROM is unusable. Every limit the supervisor layers on
    /// top (the 180 RPM stored ceiling, latched fault responses, the external watchdog) lives
    /// in that configuration, so running without it is running without them.
    ConfigUnverified(ConfigFault),
}
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

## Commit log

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2026-07-27 Lock in Matter/rs-matter, complete BOM sourcing, add CI and V2 notes
    Control plane: Matter over Wi-Fi via rs-matter + rs-matter-embassy (pure
    Rust, no_std, project-chip; its ESP examples pin exactly this firmware
    stack), used from Apple Home, replacing the HAP/HomeKit plan. Mapping,
    commissioning, and integration caveats in docs/controls.md.
    BOM: add the missing MMSZ5242B, TPD2EUSB30, JST PH/SH mating parts, the
    two PCB fab lines (V1 controller + Hall daughterboard); new Notes column
    with verified lifecycles, LCSC numbers, and stock caveats (LM2907 active
    but thin; exact MCF8316DULVRGFR not LCSC-stocked). JLCPCB is the fab;
    PCBA vs hand-population TBD.
    Also: align build.md with the test ma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
    [bom.csv]
2026-07-27 Integrate six-thread research round: MCF variant, GPIO fix, anchors, sourcing
    MCF8316DVRGFR replaces the ULV variant (identical silicon; DULV adds only
    UL 60730 recognition + a self-test library the external safety chain
    replaces); D-generation gotchas, EXT_WD wiring, ALARM on GPIO14, SPEED-pin
    sleep trap, EEPROM discipline, and the 35 RPM feasibility analysis land in
    electrical.md/controls.md.
    GPIO map verified against the ESP32-C6-MINI-1 datasheet: GPIO14 has no ADC,
    NTC moves to GPIO6.
    New docs/install.md: KB-TZ2 3/8" SS anchor selection (~7x margin, cracked
    concrete), pre-drill PT-slab verification checklist, and the Vancouver
    approval path (strata approval required; cord-and-plug 24 V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
    [bom.csv]
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2026-07-27 Apply 13-agent design review: 4 circuit blockers fixed, contract completed
    Circuit fixes in the PCB handoff: U6 persistent-lock power-up race (found
    independently by four reviewers; every cold boot latched the fan locked-out
    as drawn) fixed with a delayed-/PRE RC + Schmitt buffer; reverse-polarity
    MOSFET drain/source un-reversed; LM2907 timing cap moved to its correct
    ground node plus missing emitter load and GND pin; MCU_CLEAR_N and the
    Hall plausibility input given real GPIOs (15, 7); GPIO8/9 boot pull-ups;
    U5 /PRE hard-tied; /CLR RC removed (transition-rate spec); CPH-CPL 100 V;
    EXT_WDT registers with the inverted FAULT_MODE encoding; NTC/VBUS circuits
    specified; module bulk 22 uF.
    Overs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
    [bom.csv, test-matrix.csv]
2026-07-27 Fix-verification corrections + Simpson Titen HD anchor selection
    The adversarial delta review of commit 5bed9c1 found two of the four
    applied blocker fixes were themselves defective: the reverse-polarity
    FET "correction" had inverted a correct circuit (restored to drain-at-
    RAW24 with a do-not-fix-again rationale) and the delayed-/PRE RC could
    not meet its own >=300 ms claim at Schmitt-threshold corners (resized to
    100k/10uF with corner math, TPS7A16 DELAY cap cut to 10 nF, and the
    glitch-immunity claim rewritten honestly as ~ms diode-discharge only).
    Also from that review: SPEED_RANGE_SEL=1h added (200 Hz carrier was
    outside the register's default band), BAT54H qty 6, TACH-01B acceptance
    qu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
    [bom.csv, test-matrix.csv]
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2026-07-27 parts.md: lock ENC-100 tab clocking + clamshell split plane
    Tabs at 45/105/165/225/285/345 on r96, split plane on the 135-315 axis
    (removable half spans 315->135 and exposes the PCB face-on).
    Records the verified clearance table and the rejected phase families.
    Corrects the previous ">=20 mm margin" claim: that checked standoffs and
    anchors but not the tether slot, where the real minimum is 12.6 mm.
    MP-100 now waits only on the cable-slot angle.
    [config.rs, main.rs, mcf8316.rs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]
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2026-07-27 parts.md: dimension SP-100 anti-rotation as a keyed flange
    The July review added wrench flats to SP-100 without a size, so the part
    could not be cut. Dimensions them at 30.0 mm across flats, and keys them
    into a matching double-D pocket in MP-100 rather than relying on a wrench.
    Wrench flats alone solved the wrong problem: the flange is bench-assembled
    into a ceiling-facing recess, but the castellated nut goes on after the
    plate is anchored, when the flange is sandwiched against the slab and the
    only exposed shank is the 2.5 mm capture gap. Keying it to the plate means
    no counter-hold is needed at any point.
    Costs 6% of the flange bearing annulus (1.9 MPa at the 1.25 kN proof);
    flat interf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
    [board.rs, config.rs, main.rs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]
2026-07-27 parts.md: derive the SP-100 bottom-end stack
    Replaces "approximately Z218" and an unlocated cotter hole with real
    numbers, so SP-100 is now fully drawable. Thread ends at Z218.0; cotter
    cross-hole centreline at Z213.2.
    Both derive from fixing the retainer as a DIN 935 M12 castellated nut
    (m 15.0, m' 10.0, six 3.2 slots) with an ISO 1234 3.2 x 32 split pin.
    That puts the slot band at Z210.7-215.7, so the hole sits mid-band with
    0.9 mm clear at each end and stays inside the band across the ~+/-0.2 mm
    stack tolerance. Six castellations on a 1.75 pitch give 0.292 mm of axial
    adjustment per index step.
    Adds both fasteners to the BOM.
    [bom.csv]
2026-07-27 firmware: review fixes for the core/app split (phase A)
    Five reviewers over the phase A restructuring. Three real bugs:
    duty_for returned 2048 at the 180 RPM ceiling. The SPEED duty register is
    11-bit, so full scale aliases to zero: a maximum command would have stopped the
    fan. Only two accidental downstream clamps prevented it. Clamped at the source
    via config::SPEED_DUTY_MAX, and the test that asserted the wrap value as correct
    now asserts it can never be produced.
    MilliRpm::whole_rpm() overflowed on MilliRpm(u32::MAX), which
    milli_rpm_from_pulses deliberately manufactures from a garbage tach delta.
    Release builds wrapped it to 0 RPM, reporting a nonsense reading as "stopped" in
    exactly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
    [test-matrix.csv]
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2026-07-27 firmware: MCF I2C driver, decoded faults, interrupt-executor split (phase B)
    Three strands.
    The I2C driver. Mcf implements RegisterBus over esp-hal's async I2C, with CRC
    on by default and verified on every read - a bad checksum is a reported failure,
    not a silently retried one, because it means either the bus is corrupting data
    or our framing is wrong. It lives on the low-priority executor and talks to the
    control loop through two signals, so a hung bus can never block the state
    machine. CLR_FLT is now a real register write rather than a log line.
    Decoded fault status. Both fault-status registers (0xE0/0xE2) are polled every
    200 ms and reduced to an McfCondition: undervoltage, overvoltage,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
    [board.rs, config.rs, main.rs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]
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2026-07-27 firmware: review fixes for phase B
    Four reviewers over cffb7de. Three real defects.
    Fault-clear could never land. poll_fault issued CLR_FLT and went to SafeBoot,
    but external_fault re-evaluated MCF sources every 50 ms tick - and CLR_FLT takes
    up to 200 ms to take effect, so the fan re-faulted four ticks later and silently
    consumed the user's command. On hardware this would have meant pressing twice,
    every time, and DRV-08 flaking on the bench. SafeBoot now suppresses MCF fault
    sources for its hold and re-checks them once at exit, so a clear gets the full
    ten seconds and a genuinely persistent fault is reported once rather than
    bounced. This also absorbs MCF power-up transients, which had th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
    [board.rs, config.rs, main.rs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]
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2026-07-27 MP-100 ordered: status, BOM split, and the JLCCNC ordering playbook
    First custom part committed to metal (JLCCNC, SUS304, brushed, qty 1).
    Splits MP-100 out of the "MP-100 through ENC-100" BOM catch-all into its
    own Ordered line, adds the M3 P-clip pair, and drops the 210 dia plate
    from the raw-stock list since the part now arrives finished.
    cad/README.md gains an ordering playbook: the two-file STEP+PDF split,
    the easy-to-miss Threads "+ Add file" tapping slot, the dialog settings,
    JLC's blind-tap and thread-length DFM rules, and the fact that they hold
    no form tolerances (which is why SP-100 and MC-100/RH-100 are poor fits
    there even though MP-100 was a good one).
    Records the OnShape got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
    [bom.csv]
2026-07-27 firmware: review fixes for the tuning harness (phase C)
    Three reviewers. One critical, three major.
    Critical: esp_println takes esp-sync's raw lock, which on RISC-V clears the
    global interrupt-enable bit - not a priority mask, a full core-level disable -
    and then busy-spins up to 50k iterations when the USB FIFO is full. Streaming
    telemetry made that routine rather than rare: a paused script or a disconnected
    terminal is enough to fill the FIFO. That would mask the Priority3 interrupt the
    control loop, heartbeat, and both tach counters run on, so a stalled console
    could stop the fan - the exact inversion of the contract the executor split
    exists to enforce.
    All output, protocol frames and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
    [console.rs, main.rs, mcf.rs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]
2026-07-27 firmware: boot-time MCF configuration gate, Matter mapping, first real-silicon run
    SafeBoot's "stored configuration verified" clause is enforced now rather than
    aspirational. The I2C task produces a verdict on the MCF's stored configuration
    while the ten-second hold elapses, and the supervisor will not reach IdleOff
    without one; a failed verdict is a fault before or after boot.
    The image is a captured golden block of whole 32-bit register values, not
    invented bit fields. Bit-level layouts for the configuration block were never
    transcribed into firmware on purpose, and a golden image sidesteps the question:
    capture the block off a tuned device with `config capture`, commit it, and
    read-back-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
    [test-matrix.csv]
2026-07-27 firmware: review fixes for the configuration gate
    `config dump` through the CLI printed the first register of twenty-four and
    exited zero. `passthrough` reads exactly one reply, and dump is the one device
    command that answers with many lines, so an operator reaching for the command
    the help text advertises got a complete-looking dump that never happened. It now
    shares the whole-block collection `config capture` already had, which fails on a
    short read rather than covering only what arrived. Regression tests both ways: a
    whole block from the simulator, and a deliberately truncated link.
    A configuration-register write was budgeted 500 ms, but this branch made it also
    run a full re-verificatio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
    [console.rs, main.rs, mcf.rs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]
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2026-07-28 docs: wrap the blade-redesign session
    Sweep the BP-100 supersessions into decisions.md (rotor row),
    mechanical.md (rotor geometry pointer), and bom.csv (CF rod + LW-PLA
    lines, BA-00 note); rewrite STATE.md. Next is unchanged: the V1
    schematic. BA-00 flat adapter is the new blade-path blocker.
    [bom.csv]
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2026-07-28 docs/bom: holistic pass — MC-100 Ø180, mechanical fastener BOM, COTS verdicts
    - MC-100 OD 188 → 180 swept through parts.md, mechanical.md, build.md
    (rim margins re-checked: 7 mm past the standoff posts, ~9.7 mm at the
    tether holes, ENC-100 clearance improves)
    - Mechanical fastener set added to bom.csv line-by-line with sourcing:
    the CAD work froze every length, including the newly derived M5 × 22
    blade bolts; stale pre-raise Z values in the castellated-nut/split-pin
    lines re-based (Z196.7/218/213.2 → Z120.7/142/137.2)
    - Sourcing findings recorded: countersunk A4-80 doesn't exist at retail
    (A4-70/A2-70 fallback noted); DIN 980V oval-top nuts are too tall for
    the 5.0 mm b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
    [bom.csv]
2026-07-28 docs/bom: KD-100 goes purchased — Ø50×Ø12×6 machined washer, stack re-based
    Owner selected an Amazon lathe-machined stainless washer (5-pack ~$35)
    over the custom laser part and the MISUMI configurable spacer. The 6 mm
    thickness (vs 4) shifts the whole nut/cotter stack down 2 mm: SP-100
    thread end Z142.0 → Z144.0 (23.3 mm), cotter cross-hole Z137.2 → Z139.2,
    same 0.9 mm crown-band margins. Swept through parts.md, mechanical.md,
    blade-v2.md, bom.csv, and the envelope-check script.
    Caveats recorded: the Ø12 bore is ~zero-clearance over an M12 thread
    (verify it slides or open to Ø12.5-13); confirm austenitic grade,
    flatness, and actual thickness on arrival before drilling the cross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
    [bom.csv]
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2026-07-28 bom: Accu fastener order placed — 14 lines, $219.45 CAD landed incl DHL
    All mechanical fasteners, the M5 lock nuts (Accu HLN-M5-A4 replaced the
    BelMetric plan), Nord-Lock M6 pairs, the M3 bracket hedge kit, and the
    KD-100 DIN 440 washers flipped to Ordered (Accu 2026-07-28). Est.
    delivery 2026-07-30. Amazon washer order cancelled; OnShape reverted to
    the 4 mm stack by the owner.
    [bom.csv]
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2026-07-28 bom: DigiKey insurance cart built (Web ID 374750597); trimmer + zener swaps
    Cart holds 9 lines, $35.84 USD subtotal: LM2907 x3, TPS3435 x2,
    DRV5033 x3, MCF8316DVRGFR x2, PHR-3/PHR-2 x2, MMSZ5242B-E3-08 x5,
    3296Y-1-204LF x2, SPH-002T contacts x100 (min strip). Substitutions
    forced by live stock: 3296W -> 3296Y (W 0-stock to ~Aug 31; Y needs its
    own footprint at layout) and Diodes/onsemi zener -> Vishay
    MMSZ5242B-E3-08 (Diodes 40-wk backorder, onsemi marketplace-only).
    Thin-stock notes refreshed - LM2907 and TPS3435 stocks recovered
    (730 / 6928), which weakens the buy-now-for-insurance urgency.
    Brass rod ordered (Amazon); tach magnets and P-clips owner stock.
    [bom.csv]
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2026-07-28 bom: DigiKey cart scoped to LCSC-gap parts; five lines added
    Sourcing strategy recorded (bom/README): JLCPCB/LCSC is the default
    board-component source, owner hand-installs SMD, and the DigiKey cart
    (374750597) holds only parts the LCSC path can't reliably supply.
    Added under that lens: Coilcraft LPS4018 x2 (never on LCSC; PN suffix
    corrected -MRB -> -MRC, old revision gone), Panasonic EEU-FR1H471 x4
    (FR radials spotty on LCSC), genuine JST B3B/B2B-PH-K-S x2 each (LCSC
    carries clones), GCT USB4105-GF-A x2 (design-to-a-part-in-hand).
    Cart: $47.01 + $28 shipping (Coilcraft adds ~$8 second-warehouse
    freight) = $75.01 USD.
    [bom.csv]
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2026-07-28 bom: DigiKey order 374750597 placed — 12 lines flipped to Ordered
    The LCSC-gap electronics order is purchased (~$43.47 + $20 shipping
    USD, 12 lines, all Immediate): LM2907 x3, TPS3435 x2, DRV5033 x3,
    MCF8316DVRGFR x2, PHR-3/PHR-2 x2 each, SPH contacts x100, Vishay
    MMSZ5242B-E3-08 x5, 3296Y trimmers x2, EEU-FR1H471 x4, USB4105-GF-A
    x2, Adafruit 4209 dev cable. README order history refreshed - the
    2026-07-28 ordering campaign (Accu + Amazon + DigiKey) is closed;
    remaining purchases ride the V1 board run.
    [bom.csv]
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2026-07-29 pcb: capture SCH-01 input + SCH-02 3V3 rail, custom symbol library
    Hierarchical sheets for all seven electrical.md blocks. SCH-01 (reverse PMOS
    in the canonical drain-to-RAW24 orientation, zener clamp, TVS, bulk bank +
    DNP spare) and SCH-02 (TPSM365R6V3 with EN tied to VM24, BIAS to VOUT, mode
    solder jumper defaulted to GND/PFM, PGOOD pull-up) captured and
    connection-validated, with MPN/LCSC fields on non-generic parts.
    pcb01-parts.kicad_sym carries datasheet-verified symbols for MCF8316D
    (D-generation pinout), TPSM365R6V3, TPS7A1601, TLV1701, TPS3435 pinout C,
    and LM2907M-14. Konnect's placement path only resolves libraries from the
    installed-symbols dir, so the library is symlinked into t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
    [pcb-01.kicad_sch, sch01-input.kicad_sch, sch02-logic-rail.kicad_sch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]
2026-07-29 pcb: capture SCH-03 MCF power stage; buck inductor gate resolved
    MCF8316D captured with the D-generation pinout: charge pump, AVDD/DVDD
    bypass, aux buck (SW_BK/FB_BK/GND_BK), FG/nFAULT/I2C pull-ups, unused-pin
    terminations per the safe-defaults table, NC flags on EXT_CLK and DACOUTs,
    phases exported as PHASE_U/V/W.
    Buck inductor: SWPA4018S470MT fails the electrical.md Isat >= 910 mA gate
    (whole 4018/LPS4018 class is ~0.55 A; LPS5030 doesn't close it either and
    no 47 uH XAL40xx exists). Swapped to Sunlord SWPA6045S470MT (1.4 A Isat,
    LCSC) with LPS6225-473MRB as the DigiKey alternate; bom.csv and
    electrical.md updated together. /pcb skill gains the session's Konnect
    quirks (local-only batch l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
    [bom.csv, sch03-mcf-power.kicad_sch]
2026-07-29 pcb: capture SCH-04..07, full-project ERC clean
    Parallel agent capture of the remaining blocks: SCH-04 ESP32-C6 (full GPIO
    map, boot straps, USB chain with TPD2EUSB30 on the connector side of the
    22R), SCH-05 permission + watchdog (both '1G74s with the review-fixed /PRE
    topologies, six-BAT54H wired-OR, TPS3435 pinout C, separate 100R heartbeat
    feeds), SCH-06 analog tach (TPS7A16 protected rail with 10 nF DELAY, LM2907
    with grounded CP1 and emitter load, TLV1701 trip stage with C2 DNP ladder),
    SCH-07 connectors J1-J8 + 28 test points + DNP input-fuse footprint.
    ERC: 0 errors after PWR_FLAGs on VM24/AGND/PGND/TACH_LDO_IN and demoting
    the MCF's duplicate OUTx/VM/PGND pins to passive. Konnect n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
    [sch01-input.kicad_sch, sch03-mcf-power.kicad_sch, sch04-esp32.kicad_sch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]
2026-07-29 pcb: custom footprints (MCF RGF, TPSM RDN, TI SM8) + full footprint assignment
    pcb01-parts.pretty carries three datasheet-derived footprints: MCF8316D
    VQFN-40 RGF0040E (40 pads + 3.7x5.7 EP + 12 POFV thermal vias at 0.3 mm
    drill), TI SM8 DCT0008A with TI's 3.8 mm pad-row span (the number KiCad's
    generic SSOP-8 gets wrong), and TPSM365R6 RDN0011A. The RDN pattern's
    chained dimensions were ambiguous, so pad geometry was pixel-measured from
    the 20X/600dpi render of TI drawing 4226623/F and cross-checked against the
    direct labels; the VOUT/SW comb pads are simplified to rectangles at the
    tooth-tip boundary (noted in the footprint description).
    L1 uses KiCad's stock Sunlord SWPA6045S footprint.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
    [sch02-logic-rail.kicad_sch, sch03-mcf-power.kicad_sch, sch04-esp32.kicad_sch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]
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2026-07-29 pcb: fix PWR_FLAG instance references that broke Update-PCB
    edit_schematic_component renames the Reference property but not the
    instances block, so KiCad's netlister invented refs 01-04 for the four
    power flags and refused to add them to the board (no footprint). Patched
    the instance references to #FLG01-04; netlist verified clean (163 refs,
    no phantoms). Quirk recorded in the /pcb skill.
    [sch01-input.kicad_sch, sch06-tach.kicad_sch]
2026-07-29 pcb: board setup — 4-layer stack, outline, mounting holes, rules, net classes
    78 x 58 mm outline at (50,50), four 3.2 mm NPTH mounting holes at the
    board-local (6,6)/(72,6)/(6,52)/(72,52) positions, In1/In2 copper layers,
    JLCPCB minimums (0.16 mm trace/clearance, 0.3 mm via drill) and the
    Power24/Phase/Rail3V3/Tach12V net classes. The O8 mounting-hole copper
    keepout is a physical_clearance rule in pcb-01.kicad_dru.
    Konnect's add_layer / set_design_rules / create_netclass all write
    KiCad-5-era syntax that corrupts a KiCad 10 board (it stopped loading);
    repaired by hand, with rules and net classes relocated to the .kicad_pro
    JSON where KiCad 10 keeps them. Verified with kicad-cli pcb drc (f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
    [pcb-01.kicad_pcb]
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2026-07-29 pcb: full first-pass placement via group-planning agents + placement toolkit
    All 163 parts placed, zero courtyard overlaps (exact-geometry verified), DRC
    reduced to cosmetic classes (silkscreen text, touching testpoint courtyards,
    stock fine-pitch footprint pad gaps, lib-sync notes).
    Workflow: nine Sonnet agents each planned one coupled subcircuit from
    generated briefs (region, courtyard sizes, pin-level net adjacency, circuit
    intent); the orchestrator validated plans against pcb/tools geometry checks,
    resolved cross-group conflicts, hand-tuned two groups, solved the 25-part
    analog tach group deterministically with place_targeted.py, and applied
    everything in single file writes.
    Substantiv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
    [pcb-01.kicad_pcb]
2026-07-29 pcb: fix J2 motor connector placement + courtyard model accuracy
    J2 was rotated 90 deg wrong: mating face pointed into the board and pin 3's
    THT pad hung fully off the bottom edge (DRC copper_edge_clearance, mis-triaged
    as cosmetic). Re-placed face-south flush at the bottom edge below U1's phase
    pins; C16, R8-R10 (strap pulldowns), J4, SW3, J3, J5 shuffled to make room and
    clear the top-edge pad violation on J5. DRC copper_edge_clearance now zero.
    board_model.py courtyard parsing rewritten: the lookahead regex matched silk
    geometry against the next item's CrtYd layer tag, under-measuring courtyards
    by up to 0.34 mm (which is how J4 briefly overlapped SW3/J2). Now walks each
    fp_* item with b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
    [board_model.py, check_plan.py]
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2026-07-29 pcb: aesthetic alignment pass on placement
    Column/row alignment and grid snapping across all placement groups (62 parts
    nudged): ESP resistor banks column-aligned, permission-cluster R/TP/D columns
    on uniform pitch with aligned rows, mcf_east ladder+TP columns, lock_wd row
    snapped, tach edge columns, LDO bottom row, DNP bank pitch equalized, R39
    centered on U1's axis. Verified move-by-move against the exact courtyard
    model (aes_check.py pattern: no gap regressions below 0.15mm except bodiless
    test-point rings, documented). DRC: courtyards_overlap 16->17 (one TP ring
    pair from uniform pitch), all other classes unchanged.
    [pcb-01.kicad_pcb]
2026-07-29 pcb: review round 1 fixes — hall pull-up, ground tie, DNP marks, footprints
    13-lens board-truth review (netlist as source of truth, spec excluded to
    avoid circular validation) found and this commit fixes in the schematic:
    - R43 was a 100k pulldown to AGND on HALL_TACH; the DRV5033 is open-drain,
    so the hall line could never go high and the analog overspeed chain could
    never trip. Now 10k pull-up to 3V3 (matching the daughterboard section's
    original intent; the LM2907 spec section contradicted it).
    - PGND and AGND had no bridge anywhere (the "wide net tie" was layout-note
    prose only): added NT1 (NetTie-2_SMD_Pad2.0mm) on SCH-03.
    - C36-C40 tach filter alternates carried no DNP marki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
    [bom.csv, sch02-logic-rail.kicad_sch, sch03-mcf-power.kicad_sch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]
2026-07-29 pcb: board-side integration of review round 1
    F8 sync applied (Michael), then placement of the changed parts: NT1 net-tie
    at the PGND/AGND pour boundary north of C3/C4 (77, 77.95); J5 side-entry
    SM04B re-seated at the top-left edge (71.8, 54) rot 180, cable exit north
    over the edge, pads 0.6mm inside the copper-clearance line; C32 moved from
    the DNP bank to the LM2907 input at (115.5, 79.16) next to R45/U8 pin 1
    (TP22 nudged 0.1mm north for clearance); U12 kept in place on the smaller
    DRT-3 footprint.
    DRC improved: clearance 14 -> 10 (the U12 SOT-563 phantom fine-pitch pairs
    are gone), silk_edge 6 -> 5, no new violations in any class.
    [pcb-01.kicad_pcb]
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2026-07-29 pcb: review round 2 — safety-latch decoupling, docs, calibration rationale
    Round-2 lenses (fix-verify, placement-physics, calibration math, MCF
    register-image audit, completeness critic) confirmed every round-1 fix
    end-to-end and found: U5 and U6 — the permission and overspeed latches —
    were the only logic ICs without local decoupling (nearest 3V3 cap 13mm from
    U5). Added C42/C43 (100nF 0402) on SCH-05. J5's stale MPN field corrected
    to SM04B-SRSS-TB(LF)(SN).
    Docs: calibration section now states WHY per-unit RV1 trim is mandatory
    (LM2907 K = +/-10% => +/-20 RPM untrimmed) and the expected ~+/-10 RPM
    threshold scatter (ripple ~= hysteresis) with the C36-C40 bank as the
    remedy; open-ite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
    [sch05-permission.kicad_sch, sch07-connectors.kicad_sch]
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
